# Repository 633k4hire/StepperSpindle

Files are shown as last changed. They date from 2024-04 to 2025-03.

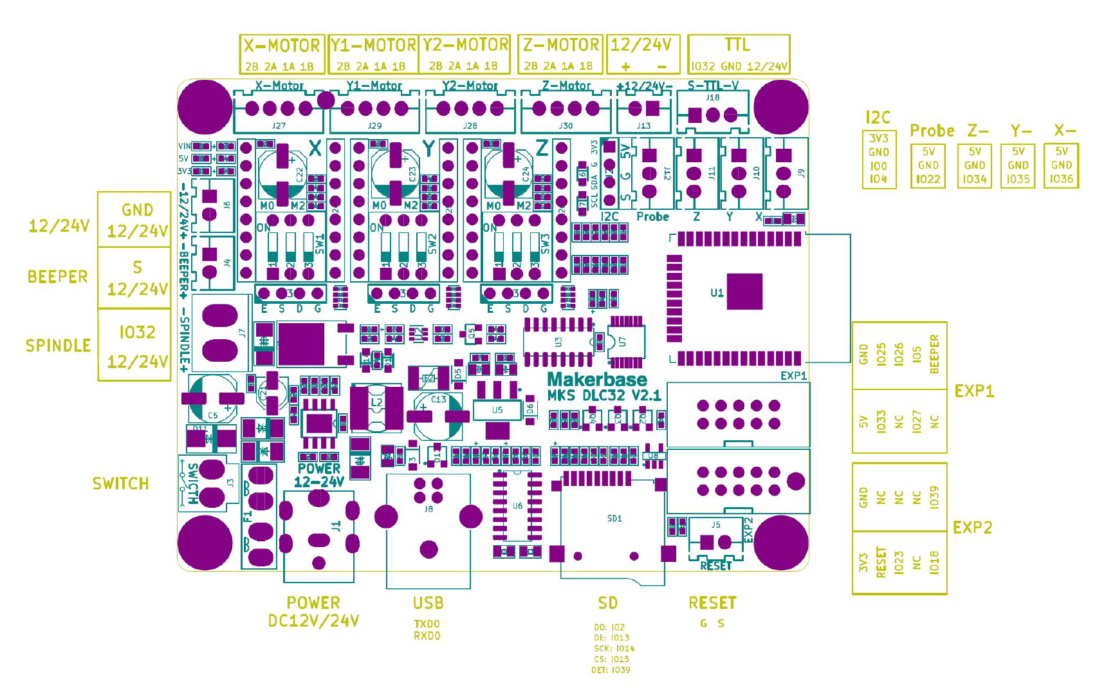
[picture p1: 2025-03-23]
mks pinout.png

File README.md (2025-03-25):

# Stepper Spindle Board

Handle a stepper motor as both a PWM-controlled spindle and a positional axis. This board provides a versatile solution for applications requiring both high-precision positioning and speed control via PWM signals.

---

## Table of Contents

- [Overview](#overview)
- [Features](#features)
- [Hardware Overview](#hardware-overview)
  - [Schematic](#schematic)
  - [Board Images](#board-images)
- [Getting Started](#getting-started)
  - [Hardware Setup](#hardware-setup)
  - [Software Setup](#software-setup)
- [Code Example](#code-example)
- [Credits](#credits)
- [License](#license)

---

## Overview

The Stepper Spindle Board is designed to handle a stepper motor in two distinct modes:

1. **PWM-Controlled Spindle Mode** – Uses PWM signals (clockwise and counter-clockwise) to control the motor speed, acting as a spindle.
2. **Positional Axis (Motion Mode)** – Provides direct positional control via a set of passthrough inputs, ideal for precise positioning tasks.

The board leverages the [FastAccelStepper Library](https://github.com/gin66/FastAccelStepper/) for high-performance stepper control and utilizes a web interface for remote control and monitoring.

---

## Features

- **Dual Operation Modes:**  
  - **Spindle Mode:** Map a 10-bit PWM input to RPM control.
  - **Motion Mode:** Directly drive the stepper motor as a positional axis.
- **Real-Time Control:**  
  - Fast, interrupt-based PWM measurements and signal passthrough.
- **Web API:**  
  - Remotely control and monitor motor operations via a built-in web server.
- **Persistent Settings:**  
  - Save and load configuration parameters using non-volatile memory.

---

## Hardware Overview

### Schematic

stepper spindle board schematic

### Board Images

- **Board Front:**

  stepper spindle board

- **3D View (Front):**

  stepper spindle board 3d

- **3D View (Back):**

  stepper spindle board 3d back

---

## Getting Started

### Hardware Setup

1. **Stepper Motor and Driver Connections:**  
   Connect the stepper motor and the corresponding driver to the board. Refer to the schematic for specific pin assignments.
   
2. **PWM Inputs for Spindle Control:**  
   Connect the PWM signals (clockwise and counter-clockwise) and the spindle enable signal as specified in the schematic.
   
3. **MKS Board Integration:**  
   The board is designed to accept directional, enable, and step signals from an MKS board. Ensure that the input pins are connected correctly:
   - **Direction:** Pin 7
   - **Enable:** Pin 8
   - **Step:** Pin 9

### Software Setup

1. **Install Required Libraries:**  
   - [FastAccelStepper Library](https://github.com/gin66/FastAccelStepper/)
   - [Preferences Library](https://github.com/espressif/arduino-esp32/tree/master/libraries/Preferences)

2. **Upload the Firmware:**  
   Use the Arduino IDE or your preferred toolchain to upload the provided firmware to your microcontroller (e.g., ESP32).

3. **Configure WiFi:**  
   Update the WiFi credentials in the main code before uploading:
   ```cpp
   const char* ssid = "SSID";
   const char* password = "PASSWORD";
   ```

---

## Code Example

Below is the main program that demonstrates how to initialize and run the Stepper Spindle Board. This code sets up the board, starts the web interface for remote control, and prints status messages to the Serial monitor every second.

```cpp
#include <Arduino.h>
#include "StepperController.h"
#include "StepperApi.h"

// Global instances
StepperController sc;
StepperApi stepperApi(&sc);

unsigned long previousMillis = 0;
const long interval = 1000; // Interval at which to print status to Serial (1 second)

// WiFi credentials (update these with your network details)
const char* ssid = "SSID";
const char* password = "PASSWORD";

void setup() {
    Serial.begin(115200);
    delay(1000);

    // Setup the stepper controller
    sc.setup();
    
    // Start the web interface (this serves the dashboard and REST endpoints)
    stepperApi.begin(ssid, password);
}

void loop() {
    // Run the stepper controller's loop for real-time control and PWM measurement
    sc.loop();

    // Print status to Serial every second for debugging purposes
    unsigned long currentMillis = millis();
    if (currentMillis - previousMillis >= interval) {
        previousMillis = currentMillis;
        String mode = sc.getMode();
        String spindleInfo = sc.getSpindleInfo();

        if (mode == "Spindle") {
            Serial.printf("Current Mode: %s, Spindle Info: %s\n", mode.c_str(), spindleInfo.c_str());
        } else {
            Serial.printf("Current Mode: %s\n", mode.c_str());
        }
    }
}
```

---

## Credits

- **FastAccelStepper Library:**  
  [FastAccelStepper](https://github.com/gin66/FastAccelStepper/)

Special thanks to all contributors and the community that supports the development of advanced stepper motor control solutions.

---

## License

MIT License,

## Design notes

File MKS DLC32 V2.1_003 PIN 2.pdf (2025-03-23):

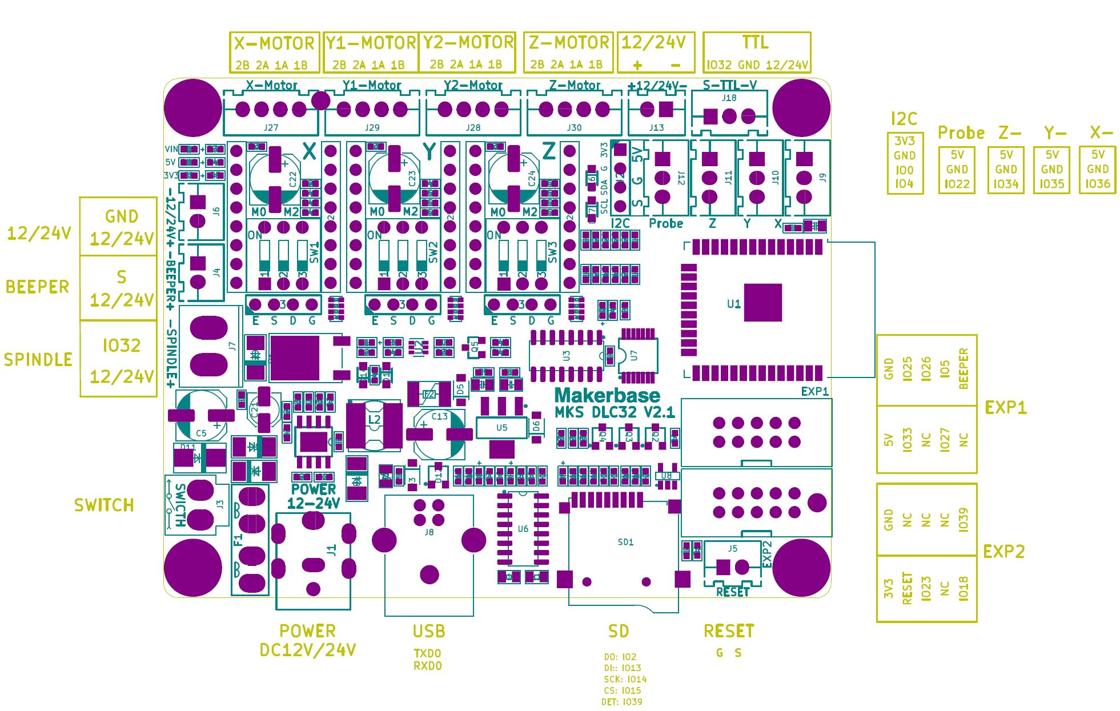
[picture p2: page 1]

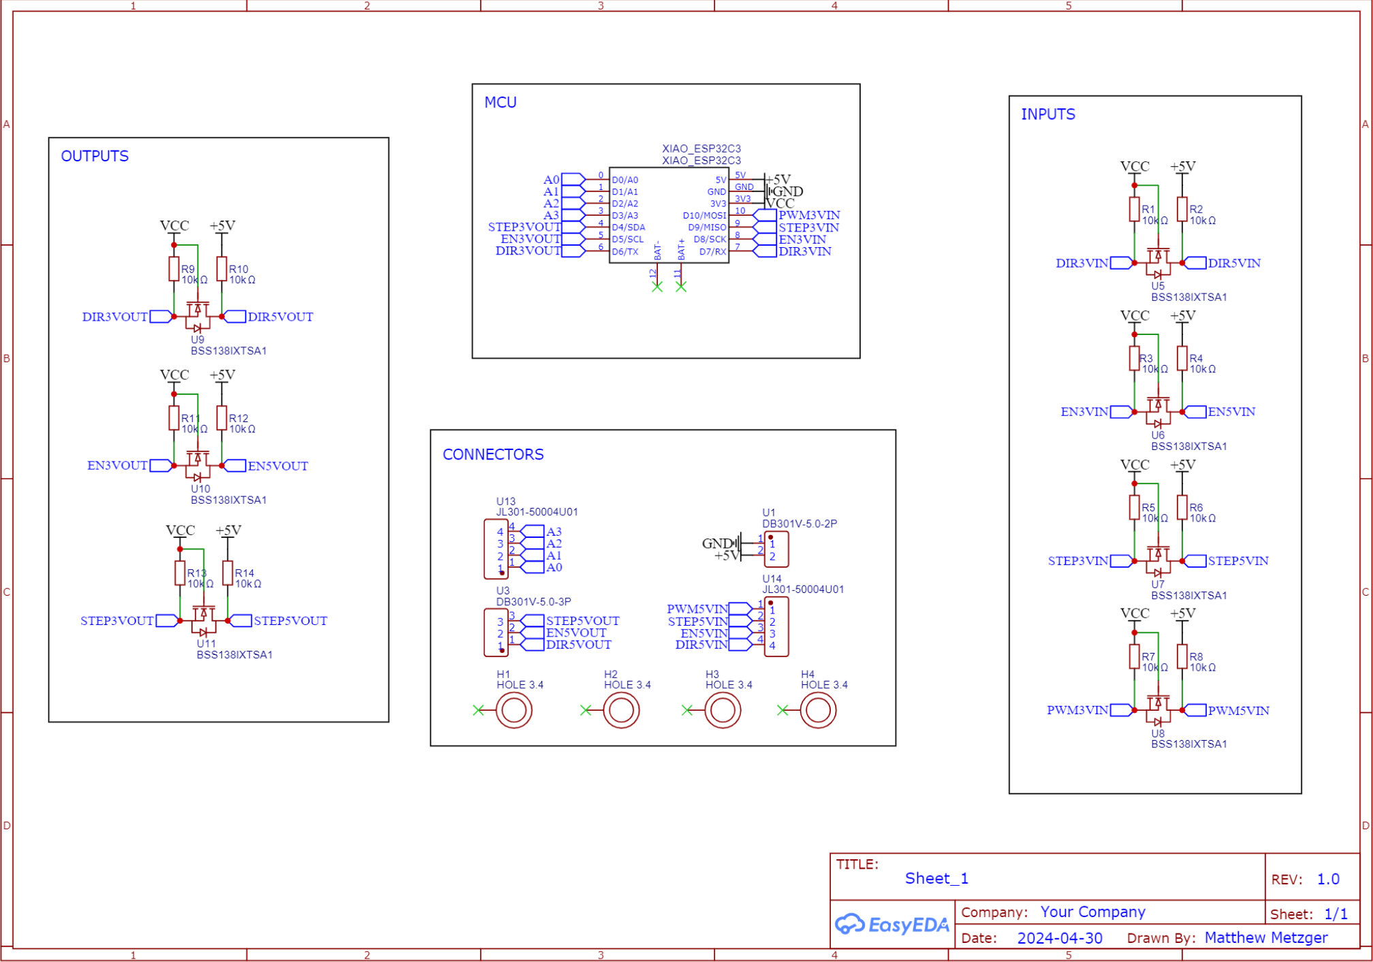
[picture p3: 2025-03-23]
stepper spindle board schematic.PNG

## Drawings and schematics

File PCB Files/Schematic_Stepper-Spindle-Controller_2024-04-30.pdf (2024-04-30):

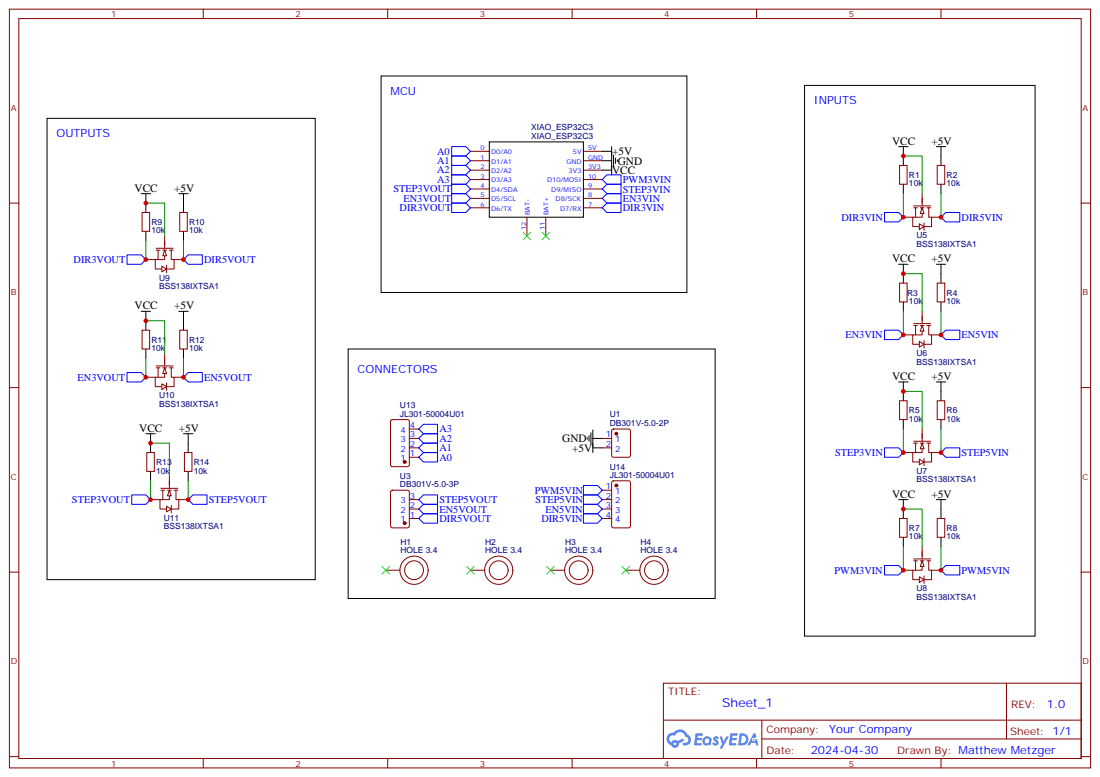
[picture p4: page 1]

Drawn By: Matthew Metzger

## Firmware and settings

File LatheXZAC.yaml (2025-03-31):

board: MKS-DLC32 V2.1
name: XZACt_MiniLathe
meta: (3/24/2025) by Matthew Metzger
kinematics:
  Cartesian:

stepping:
  engine: I2S_STATIC
  idle_ms: 0
  pulse_us: 4
  dir_delay_us: 1
  disable_delay_us: 0
axes:
  shared_stepper_disable_pin: i2so.0
  x:
    steps_per_mm: 320
    max_rate_mm_per_min: 5000.0
    acceleration_mm_per_sec2: 500
    max_travel_mm: 64
    soft_limits: true
    homing:
      cycle: 1
      positive_direction: true
      mpos_mm: 64.000
      feed_mm_per_min: 600.000
      seek_mm_per_min: 1000.000
      settle_ms: 500
      seek_scaler: 1.100
      feed_scaler: 1.100
    motor0:      
      limit_neg_pin: gpio.36:low      
      hard_limits: true
      pulloff_mm: 2
      stepstick:
        step_pin: i2so.1
        direction_pin: i2so.2     
  z:
    steps_per_mm: 320
    max_rate_mm_per_min: 5000
    acceleration_mm_per_sec2: 500
    max_travel_mm: 107
    soft_limits: true
    homing:
      cycle: 0
      positive_direction: true
      mpos_mm: 107.000
      feed_mm_per_min: 600.000
      seek_mm_per_min: 1000.000
      settle_ms: 500
      seek_scaler: 1.100
      feed_scaler: 1.100
    motor0:
      limit_all_pin: NO_PIN
      limit_neg_pin: gpio.34:low
      limit_pos_pin: NO_PIN
      hard_limits: true
      pulloff_mm: 2
      stepstick:
        step_pin: i2so.3
        direction_pin: i2so.4       
  a:
    steps_per_mm: 320
    max_rate_mm_per_min: 1000.0
    acceleration_mm_per_sec2: 100.0
    max_travel_mm: 100000
    soft_limits: false    

    motor0:
      limit_all_pin: NO_PIN
      limit_neg_pin: NO_PIN
      limit_pos_pin: NO_PIN
      hard_limits: false
      pulloff_mm: 1.000
      stepstick:
        step_pin: i2so.7
        direction_pin: gpio.5 
  c:
    steps_per_mm: 533.333
    max_rate_mm_per_min: 2000
    acceleration_mm_per_sec2: 75
    max_travel_mm: 100000
    soft_limits: false
    motor0:
      limit_all_pin: NO_PIN
      limit_neg_pin: NO_PIN
      limit_pos_pin: NO_PIN
      hard_limits: false
      pulloff_mm: 1
      stepstick:
        step_pin: i2so.5
        direction_pin: i2so.6 
i2so:
  bck_pin: gpio.16
  data_pin: gpio.21
  ws_pin: gpio.17

spi:
  miso_pin: gpio.12
  mosi_pin: gpio.13
  sck_pin: gpio.14

sdcard:
  cs_pin: gpio.15
  card_detect_pin: NO_PIN

control:
  safety_door_pin: NO_PIN
  reset_pin: NO_PIN
  feed_hold_pin: NO_PIN
  cycle_start_pin: NO_PIN
  macro0_pin: NO_PIN
  macro1_pin: NO_PIN
  macro2_pin: NO_PIN
  macro3_pin: NO_PIN

macros:
  startup_line0:
  startup_line1:
  macro0: $SD/Run=lasertest.gcode
  macro1: $SD/Run=home.gcode
  macro2:
  macro3:

coolant:
  flood_pin: NO_PIN
  mist_pin: NO_PIN
  delay_ms: 0

probe:
  pin: gpio.22
  check_mode_start: true

HBridge:
  pwm_hz: 5000
  output_cw_pin: gpio.25
  output_ccw_pin: gpio.26 
  enable_pin: gpio.27
  disable_with_s0: true
  s0_with_disable: true
  spinup_ms: 1000
  spindown_ms: 1000
  tool_num: 5
  speed_map: 0=0.000% 2000=100.000%
  off_on_alarm: true
  atc:
  m6_macro: $SD/Run=tool_change.gcode


user_outputs:
  analog0_pin: NO_PIN
  analog1_pin: NO_PIN
  analog2_pin: NO_PIN
  analog3_pin: NO_PIN
  analog0_hz: 5000
  analog1_hz: 5000
  analog2_hz: 5000
  analog3_hz: 5000
  digital0_pin: gpio.5
  digital1_pin: NO_PIN
  digital2_pin: NO_PIN
  digital3_pin: NO_PIN

start:
  must_home: false

status_outputs:
  report_interval_ms: 500
  idle_pin: NO_PIN
  run_pin: NO_PIN
  hold_pin: NO_PIN
  alarm_pin: NO_PIN
  door_pin: NO_PIN

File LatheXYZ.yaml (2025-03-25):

board: MKS-DLC32 V2.1
name: LatheXYZ
meta: (04.15.24) by Matthew Metzger
kinematics:
  Cartesian:

stepping:
  engine: I2S_STATIC
  idle_ms: 0
  pulse_us: 4
  dir_delay_us: 1
  disable_delay_us: 0
axes:
  shared_stepper_disable_pin: I2SO.0
  x:
    steps_per_mm: 320.0
    max_rate_mm_per_min: 5000.0
    acceleration_mm_per_sec2: 500.0
    max_travel_mm: 64.000
    soft_limits: true
    homing:
      cycle: 2
      positive_direction: true
      mpos_mm: 64.000
      feed_mm_per_min: 600.000
      seek_mm_per_min: 1000.000
      settle_ms: 500
      seek_scaler: 1.100
      feed_scaler: 1.100

    motor0:
      limit_neg_pin: gpio.36:low
      hard_limits: false
      pulloff_mm: 2.000
      stepstick:
        step_pin: I2SO.1
        direction_pin: I2SO.2

  y:
    steps_per_mm: 533.333
    max_rate_mm_per_min: 2000.000
    acceleration_mm_per_sec2: 75.000
    max_travel_mm: 100000.000
    soft_limits: false
    homing:
      cycle: 0
      positive_direction: false
      mpos_mm: 0.000
      feed_mm_per_min: 300.000
      seek_mm_per_min: 300.000
      settle_ms: 500
      seek_scaler: 1.100
      feed_scaler: 1.100

    motor0:
      limit_neg_pin: NO_PIN
      hard_limits: false
      pulloff_mm: 2.000
      stepstick:
        step_pin: I2SO.5
        direction_pin: I2SO.6:low

  z:
    steps_per_mm: 320.0
    max_rate_mm_per_min: 10000.000
    acceleration_mm_per_sec2: 500.000
    max_travel_mm: 107.000
    soft_limits: true
    homing:
      cycle: 1
      positive_direction: true
      mpos_mm: 107.000
      feed_mm_per_min: 600.000
      seek_mm_per_min: 1000.000
      settle_ms: 500
      seek_scaler: 1.100
      feed_scaler: 1.100

    motor0:
      limit_neg_pin: gpio.34:low
      hard_limits: false
      pulloff_mm: 1.000
      stepstick:
        step_pin: I2SO.3
        direction_pin: I2SO.4

i2so:
  bck_pin: gpio.16
  data_pin: gpio.21
  ws_pin: gpio.17

spi:
  miso_pin: gpio.12
  mosi_pin: gpio.13
  sck_pin: gpio.14

sdcard:
  cs_pin: gpio.15
  card_detect_pin: NO_PIN

control:
  safety_door_pin: NO_PIN
  reset_pin: NO_PIN
  feed_hold_pin: NO_PIN
  cycle_start_pin: NO_PIN
  macro0_pin: NO_PIN
  macro1_pin: NO_PIN
  macro2_pin: NO_PIN
  macro3_pin: NO_PIN

macros:
  startup_line0:
  startup_line1:
  macro0: $SD/Run=lasertest.gcode
  macro1: $SD/Run=home.gcode
  macro2:
  macro3:

coolant:
  flood_pin: NO_PIN
  mist_pin: NO_PIN
  delay_ms: 0

probe:
  pin: gpio.22
  check_mode_start: true

Laser:
  pwm_hz: 5000
  #L on Beeper / IN on TTL
  output_pin: gpio.32
  enable_pin: I2SO.7
  disable_with_s0: false
  s0_with_disable: false
  tool_num: 0
  speed_map: 0=0.000% 0=12.500% 1700=100.000%
# 135=0mA 270=5mA 400=10mA 700=16mA
user_outputs:
  analog0_pin: NO_PIN
  analog1_pin: NO_PIN
  analog2_pin: NO_PIN
  analog3_pin: NO_PIN
  analog0_hz: 5000
  analog1_hz: 5000
  analog2_hz: 5000
  analog3_hz: 5000
  digital0_pin: NO_PIN
  digital1_pin: NO_PIN
  digital2_pin: NO_PIN
  digital3_pin: NO_PIN

start:
  must_home: false

# 5,18,19,22,23,25,26,27,32,33,39,I2SO.7
# SDA 0 / SCL 4

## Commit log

2024-04-30 pcb files added
    [PCB_Stepper-Spindle-Controller_2024-04-30.pcbdoc, SCH_Stepper-Spindle-Controller_2024-04-30.schdoc]
2024-04-30 fixed pin issues
2024-05-02 updated pwm logic
2024-05-02 changed to RMT. PCNT not avail esp32c3
2025-03-23 new interface and pin defs
2025-03-27 fixed encoder
2025-03-31 Working XZC mode controller with homing
